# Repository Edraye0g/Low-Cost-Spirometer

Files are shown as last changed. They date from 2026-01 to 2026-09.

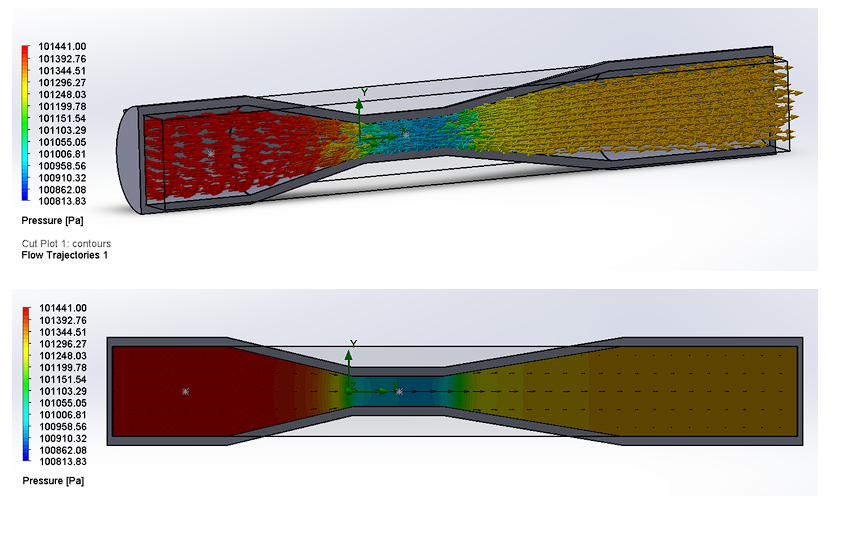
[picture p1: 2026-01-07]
figs, maps and diagrams/Screenshot 2026-01-07 191536.png

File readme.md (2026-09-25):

# Low-Cost Spirometer Design and Validation Document
(Tushil|Rayeed|Borshon|Nabil|Fuad)
## 1. Objective

The primary objectives of this experiment are given below:

* To design and simulate a Venturi-based transducer capable of measuring human respiratory flow rates (approx. $0\text{--}300\text{ L/min}$).

* To analyze the differential pressure generated across a $30\text{ mm}$ to $10\text{ mm}$ constriction using Computational Fluid Dynamics (Solidworks and SimScale).

* To implement a microcontroller-based data acquisition system using the MPX5010DP sensor to calculate real-time Flow Rate and Tidal Volume.

---

## 2. Introduction

### 2.1 Clinical Significance

Respiratory diseases, particularly Chronic Obstructive Pulmonary Disease (COPD) and Asthma, represent a major global health burden. According to the World Health Organization (WHO), COPD is the third leading cause of death worldwide, causing 3.23 million deaths in 2019. The primary diagnostic tool for these conditions is Spirometry, a pulmonary function test that measures the volume and speed of air inhaled and exhaled.

Key parameters measured include **Tidal Volume ($V_T$)**, the volume of air moved during normal breathing, and **Forced Vital Capacity (FVC)**, the total amount of air exhaled during a forced breath. Accurate monitoring of these parameters is critical for diagnosing airway obstruction and tracking disease progression.

### 2.2 Problem Statement

Standard clinical spirometers, often based on Fleisch pneumotachographs or ultrasonic sensors, provide high accuracy but come with significant barriers for low-resource settings. Commercial units typically cost between $1,70,000\text{ Tk}$ and $3,400\text{ Tk}$ and require frequent calibration and specialized maintenance. In rural healthcare facilities or developing regions, the lack of affordable diagnostic instrumentation leads to underdiagnosis and delayed treatment. Consequently, there is a pressing engineering need to develop low-cost, portable digital spirometers that maintain acceptable accuracy using off-the-shelf components.

### 2.3 Engineering Principle: The Venturi Effect

To address the cost barrier, this project utilizes a Venturi-based differential pressure transducer. Unlike turbine flow meters (which suffer from mechanical inertia) or hot-wire anemometers (which are fragile and computationally complex), a Venturi meter has no moving parts, making it robust and easy to sterilize.

The operation relies on the conservation of mass (Continuity Equation) and energy (Bernoulli's Principle). As air flows through a converging pipe, the fluid velocity must increase to pass through the narrower throat.

According to Bernoulli's Principle, this increase in kinetic energy (velocity) results in a simultaneous decrease in potential energy (static pressure). By placing pressure taps at the inlet (**Point 1**) and the throat (**Point 2**), the differential pressure ($\Delta P = P_1 - P_2$) can be measured.

### 2.4 Mathematical Derivation

The relationship between the measured pressure difference and the volumetric flow rate ($Q$) is derived for an incompressible fluid (approximated for low-speed airflow) as follows:
$$Q = C_d A_2 \sqrt{\frac{2\Delta P}{\rho(1 - \beta^4)}} \quad \text{--- (1)}$$

Where:

* $Q$: Volumetric flow rate ($\text{m}^3/\text{s}$)
* $C_d$: Discharge coefficient (accounts for viscous losses, typically $0.96\text{--}0.98$)
* $A_2$: Cross-sectional area of the throat ($\text{m}^2$)
* $\rho$: Density of air (approx. $1.225\text{ kg/m}^3$ at sea level)
* $\beta$: The Beta ratio ($d_{\text{throat}} / d_{\text{inlet}}$)

This non-linear relationship implies that flow is proportional to the square root of pressure ($Q \propto \sqrt{\Delta P}$). The system uses a differential pressure sensor (MPX5010DP) to convert $\Delta P$ into an analog voltage. The microcontroller then linearizes this signal and performs numerical integration over time ($V = \int Q \, dt$) to derive the total volume of air exhaled.

---

## 3. Literature Review

Recent developments in frugal biomedical engineering have demonstrated the viability of Venturi-based systems for respiratory monitoring. In a 2025 study, Wallace et al. designed and validated a low-cost spirometer utilizing the Venturi principle and 3D-printing technology for low-resource settings. Their device, which integrated a differential pressure sensor (MPX5010DP) with an Arduino microcontroller, was tested against a standard 2-liter calibration pump. The study reported a mean measured volume of $1.983\text{ L}$, resulting in an accuracy error of only $1.53\%$. Furthermore, their research highlighted that a throat diameter of approximately $10\text{ mm}$ is optimal for balancing sensor resolution with the maximum peak expiratory flow (PEF) of human subjects. This validates the design approach adopted in our experiment, confirming that differential pressure transduction is a reliable method for estimating tidal volume without expensive mechanical turbines.

---

## 4. Apparatus Required

### A. Mechanical & Simulation Tools

* **CAD Software:** SolidWorks (for geometry modeling)
* **CFD Solver:** SimScale (OpenFOAM based) and SolidWorks for pressure validation
* **3D Printer:** For fabricating the physical Venturi tube (PLA material)
* Scalp Vein Set

### B. Electronics Hardware

* **Microcontroller:** Arduino Uno (ATmega328P)
* **Pressure Sensor:** NXP MPX5010DP (Range: $0\text{--}10\text{ kPa}$, Sensitivity: $450\text{ mV/kPa}$)
* **Display:** 0.96" OLED Display ($128 \times 64$, I2C)
* Resistors
* Wires (Male to Male)

---

## 5. Design & Simulation

### Step 1: Mechanical Design

A Venturi tube was modeled with an ISO-standard inlet diameter of $30\text{ mm}$ to fit standard mouthpieces. To ensure a measurable pressure drop without exceeding the sensor's limit during peak expiration, the throat diameter was optimized to $10\text{ mm}$.

### Step 2: CFD Simulation (SimScale and SOLIDWORKS)

A steady-state simulation was performed to validate the design:

* **Physics:** Incompressible Fluid Flow.
* **Boundary Conditions:**
* **Inlet:** Velocity Inlet set to $3\text{ m/s}$ and $6\text{ m/s}$
* **Outlet:** Pressure Outlet at $0\text{ Pa}$ (Gauge)
* **Turbulence Model:** k-omega SST
* **Results:** The simulation predicted a pressure drop of $0.497\text{ kPa}$ and $2.021\text{ kPa}$.

### Step 3: Simulation Validation

**Table 1: Venturi Tube CFD Simulation Results for the value of constant $K$**

| Parameter | Inlet Velocity $3\text{ m/s}$ | Inlet Velocity $6\text{ m/s}$ |
| --- | --- | --- |
| **Density ($\text{kg/m}^3$)** | 1.20508| 1.20508|
| **Static Pressure inlet ($\text{kPa}$)** | 101.441| 101.795|
| **Static Pressure throat ($\text{kPa}$)** | 100.944| 99.774|
| **Pressure Differential $\Delta P$ ($\text{kPa}$)** | 0.497| 2.021|
| **Avg Static Pressure ($\text{kPa}$)** | 101.383| 101.561|
| **Avg Velocity ($\text{m/s}$)** | 3.0039| 6.023|
| **Volume Flow Rate ($\text{m}^3/\text{s}$)** | 0.00207598| 0.0042|
| **Value of $K$** | 201.2| 176.6|

$$\text{Average value of } K = \frac{201.2 + 176.6}{2} = 186.4$$

### Step 4: Signal Processing Algorithm & Arduino Simulation

The MPX5010DP outputs an analog voltage proportional to pressure. The Arduino performs the following operations:

1. **Analog-to-Digital Conversion (ADC):** Reads the $0\text{--}5\text{V}$ signal as a $0\text{--}1023$ integer.
2. **Pressure Calculation:** Converts voltage to Pascals.
3. **Flow Calculation:** Applies the simplified transfer function $Q = k\sqrt{\Delta P}$, where $k$ was determined to be $186.4$.
4. **Volume Integration:** Calculates Tidal Volume ($V_{\text{tidal}}$) by integrating flow over time:

$$V_{\text{tidal}} = \sum_{t=0}^{T} (Q_t \times \Delta t)$$

**Sensor Characterization:**
* **Sensitivity:** $0.45\text{ V/kPa}$
* **Zero Offset:** $\approx 0.20\text{ V}$ (Measured experimentally.
* **Algorithm Implementation:** $\text{Flow Rate} = Q_{\text{real}} = 186 \times \sqrt{P_{\text{measured}}}$

> **Fig. 3:** Spirometer operation sequence flowchart:
> 
> 
> `Start (Power on device)` $\rightarrow$ `Initialize System` $\rightarrow$ `Calibration (Calculate zero offset)` $\rightarrow$ `Read Sensor (Pin A0)` $\rightarrow$ `Filter Noise` $\rightarrow$ `Calculate Physics` $\rightarrow$ `Calculate Volume` $\rightarrow$ `Update Display (OLED)` $\rightarrow$ `Repeat`.
> 
> 

---

## 6. Methodology

### 6.1 Prototype Fabrication and Assembly

The Venturi tube was fabricated using Fused Deposition Modeling (FDM) 3D printing with Polylactic Acid (PLA) filament.

* **Print Settings:** To ensure air-tightness and structural integrity under pressure, the model was printed with 100% infill and a layer height of $0.12\text{ mm}$.

* **Sensor Integration:** The MPX5010DP differential pressure sensor was coupled to the Venturi tube using $4\text{ mm}$ silicone tubing. The "Pressure Port" ($P_1$) was connected to the inlet tap, and the "Vacuum Port" ($P_2$) was connected to the throat tap to measure the pressure drop ($\Delta P$).

* **Electronics:** The sensor output was wired to Analog Pin A0 of the microcontroller.

### 6.2 Calibration Protocol

Before human testing, a zero-point calibration was performed to eliminate sensor drift:

1. The device was placed on a stable, vibration-free surface.

2. The airflow path was left open to ambient air (zero flow condition).

3. The microcontroller recorded 50 consecutive readings over 0.5 seconds.

4. The average of these readings was stored as the `sensorOffset` voltage, which was subtracted from all subsequent measurements during the trial.

### 6.3 Human Testing Procedure

To validate the system's ability to measure Tidal Volume ($V_T$), tests were conducted on four healthy subjects (ages 20–24). The following protocol was strictly observed:

* **a) Sterilization:** The mouthpiece was sanitized with 70% isopropyl alcohol between subjects to maintain hygiene.

* **b) Posture:** Subjects were seated in an upright position with their feet flat on the floor to maximize thoracic expansion.

* **c) Sealing:** Subjects were instructed to hold the device horizontally and form a tight seal around the mouthpiece with their lips to prevent air leakage.

* **d) The Maneuver:**
1. *Phase 1 (Stabilization):* The subject breathed normally away from the device for 30 seconds.
2. *Phase 2 (Inhalation):* The subject took a standard resting inhalation.
3. *Phase 3 (Exhalation):* The subject exhaled normally (not forcefully) into the Venturi tube until their lungs reached functional residual capacity.

* **e) Data Logging:** The microcontroller sampled pressure data at $10\text{ Hz}$. The computed Flow Rate ($\text{L/min}$) and Accumulated Volume ($\text{L}$) were visualized in real-time on the OLED display.

### 6.4 Safety Precautions

* The device was operated at low voltages ($5\text{V}$) to ensure electrical safety.
* To prevent hyperventilation or dizziness, subjects were given a 60-second rest period between consecutive trials.

---

## 7. Verifying Low Cost

**Table 2: Components and Price Breakdown**

| No. | Component | Price (Tk.) |
| --- | --- | --- |
| 1 | MPX5010DP (Differential Pressure Sensor) | 2400|
| 2 | Arduino Uno R3 | 400|
| 3 | 0.96" OLED Display ($128 \times 64$, I2C) | 300|
| 4 | Breadboard | 50|
| 5 | 3D Printing | 200|
| 6 | Scalp Vein Set $\times 2$ | 20|
| **Total** |  | **$\approx 3,400\text{ Tk.}$**<br> |

---

## 8. Discussion

A comparative study was conducted on four subjects (**Ananna, Nowroz, Shakil, and Rayeed**). Their Tidal Volume ($V_T$) was measured first using a standard commercial spirometer (Control) and subsequently using the designed low-cost Venturi spirometer (Test).

### 8.1 Quantitative Performance

* **High Accuracy Cases:** For subjects Nowroz and Shakil, the device performed with high precision.

* **Nowroz:** Prototype $\approx 0.27\text{ L}$ vs. Standard $\approx 0.25\text{ L}$ (Difference: $+0.02\text{ L}$).

* **Shakil:** Prototype $\approx 0.42\text{ L}$ vs. Standard $\approx 0.45\text{ L}$ (Difference: $-0.03\text{ L}$).

* *Indication:* For low-to-medium flow rates, the calibrated transfer function is highly effective.

* **Deviation in Higher Volumes:** For subjects Ananna and Rayeed, a noticeable "underestimation" trend was observed.

* **Ananna:** Standard $\approx 0.53\text{ L}$ vs. Prototype $\approx 0.40\text{ L}$ (Error: $-24\%$).

* **Rayeed:** Standard $\approx 0.55\text{ L}$ vs. Prototype $\approx 0.46\text{ L}$ (Error: $\approx -16\%$).

### 8.2 Error Analysis & Engineering Constraints

1. **Air Leakage:** Minor air leakage at the interface between the rigid 3D-printed PLA mouthpiece and the subject's mouth caused exhaled air to bypass the Venturi throat.

2. **Discharge Coefficient Non-Linearity:** The algorithm assumes a constant $C_d$, but $C_d$ varies with Reynolds number. At higher flow rates, turbulence causes energy losses not fully captured by $Q = k\sqrt{P}$.

3. **Sensor Response Lag & Sampling Rate:** Numerical integration ($\sum \text{Flow} \times \Delta t$) sampled at $10\text{ Hz}$ may miss the rapid peak flow of a strong breath, leading to volume under-calculation.

### 8.3 Economic Feasibility (Cost-Benefit Analysis)

* **Traditional Device Cost:** $\approx 170,000\text{ BDT (Tk)}$

* **Low-Cost Prototype Cost:** $\approx 3,400\text{ BDT (Tk)}$

* **Cost Reduction:** $\approx 97.8\%$ (Roughly 45 times cheaper)

### 8.4 The Cost-Utility Trade-off

While standard spirometers ($170,000\text{ Tk}$) are necessary for diagnostic confirmation requiring $<3\%$ error, the proposed device ($3,400\text{ Tk}$) is ideal for mass screening in rural healthcare centers (Upazila Health Complexes). It effectively distinguishes between normal and abnormal respiratory patterns at a fraction of the cost.

### 8.5 Conclusion on Viability

The prototype successfully categorizes patients within their correct tidal volume ranges. Future iterations can bridge the accuracy gap by implementing a non-linear calibration curve via software and a silicone-sealed mouthpiece via hardware.

---

## 9. References

1. World Health Organization (WHO), "Chronic obstructive pulmonary disease (COPD)," Fact sheet. [Online]. Available: [https://www.who.int/news-room/fact-sheets/detail/chronic-obstructive-pulmonary-disease-(copd)](https://www.who.int/news-room/fact-sheets/detail/chronic-obstructive-pulmonary-disease-(copd)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)

2. J. E. Hall, M. E. Hall, and A. C. Guyton, *Guyton and Hall textbook of medical physiology*, 14th edition. Philadelphia, PA: Elsevier, 2021.

3. C. W. Carspecken, C. Arteta, and G. D. Clifford, "TeleSpiro: A low-cost mobile spirometer for resource-limited settings," in *2013 IEEE Point-of-Care Healthcare Technologies (PHT)*, Bangalore, India: IEEE, Jan. 2013, pp. 144-147. doi: `10.1109/PHT.2013.6461305`.

4. B. R. Munson, Ed., *Fundamentals of fluid mechanics*, 7th ed. Hoboken, NJ: Wiley, 2013.

5. J. Wallace, P. C. Rifá, T. Kannathasan, C. F. Hayfron-Benjamin, P. Anyanwu, and D. Piaggio, "Design, Manufacture and Validation of a Spirometry Device aimed for Low-Resource Settings," June 11, 2025, *In Review*. doi: `10.21203/rs.3.rs-6812011/v1`.

---

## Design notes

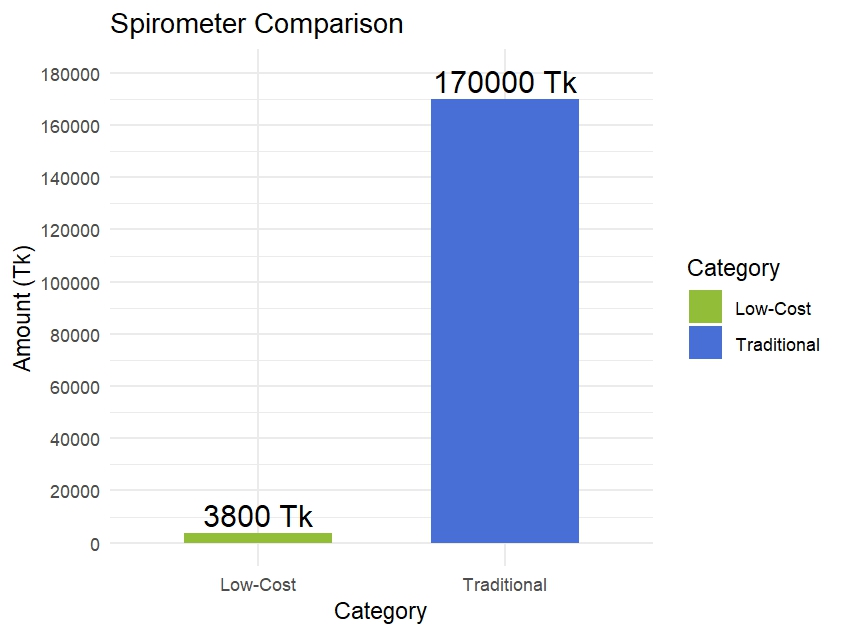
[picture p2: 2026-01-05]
spirometer comp.jpeg

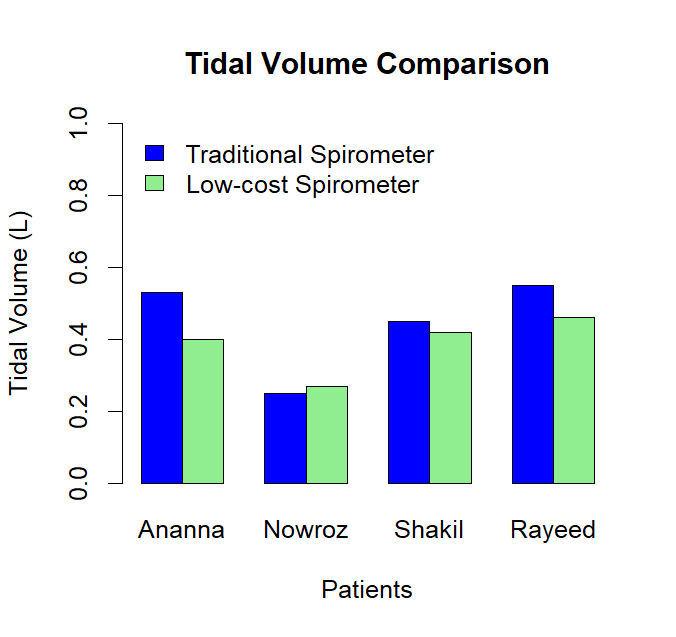
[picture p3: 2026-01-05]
comparison with patients.png

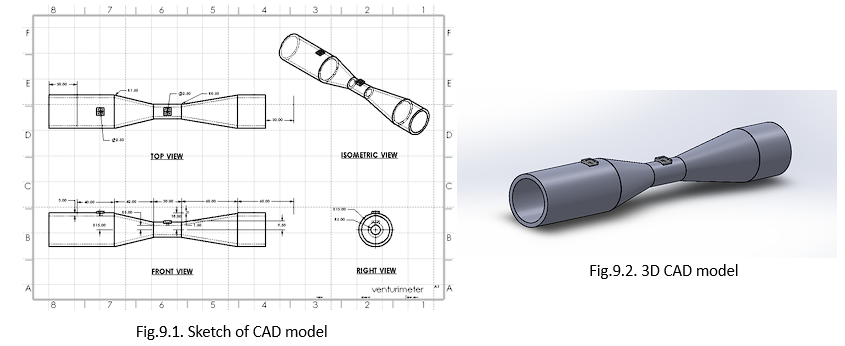
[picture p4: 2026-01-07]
figs, maps and diagrams/Screenshot 2026-01-07 191712.png

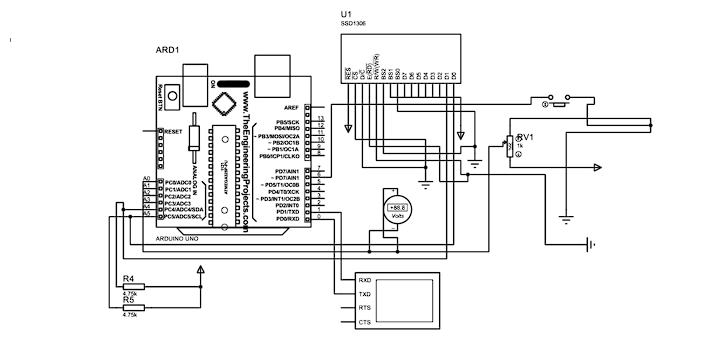
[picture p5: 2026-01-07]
figs, maps and diagrams/Screenshot 2026-01-07 191753.png

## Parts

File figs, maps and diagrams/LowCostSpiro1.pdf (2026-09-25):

## 1. Objective

The primary objectives of this experiment are given below:

- To design and simulate a Venturi-based transducer capable of measuring human respiratory flow rates (approx. 0–300 L/min).
- To analyze the differential pressure generated across a 30mm to 10mm constriction using Computational Fluid Dynamics (Solidworks and SimScale).
- To implement a microcontroller-based data acquisition system using the MPX5010DP sensor to calculate real-time Flow Rate and Tidal Volume.

## 2. Introduction

### 2.1 Clinical Significance

Respiratory diseases, particularly Chronic Obstructive Pulmonary Disease (COPD) and Asthma, represent a major global health burden. According to the World Health Organization (WHO), COPD is the third leading cause of death worldwide, causing 3.23 million deaths in 2019[1]. The primary diagnostic tool for these conditions is Spirometry, a pulmonary function test that measures the volume and speed of air inhaled and exhaled.

Key parameters measured include Tidal Volume (VT), the volume of air moved during normal breathing, and Forced Vital Capacity (FVC), the total amount of air exhaled during a forced breath [2]. Accurate monitoring of these parameters is critical for diagnosing airway obstruction and tracking disease progression.

### 2.2 Problem Statement

Standard clinical spirometers, often based on Fleisch pneumotachographs or ultrasonic sensors, provide high accuracy but come with significant barriers for low-resource settings. Commercial units typically cost between 1,70,000Tk and 3,400Tk and require frequent calibration and specialized maintenance[3]. In rural healthcare facilities or developing regions, the lack of affordable diagnostic instrumentation leads to underdiagnosis and delayed treatment. Consequently, there is a pressing engineering need to develop low-cost, portable digital spirometers that maintain acceptable accuracy using off-the-shelf components.

### 2.3 Engineering Principle: The Venturi Effect

To address the cost barrier, this project utilizes a Venturi-based differential pressure transducer. Unlike turbine flow meters (which suffer from mechanical inertia) or hot-wire anemometers (which are fragile and computationally complex), a Venturi meter has no moving parts, making it robust and easy to sterilize.

The operation relies on the conservation of mass (Continuity Equation) and energy (Bernoulli’s Principle). As air flows through a converging pipe, the fluid velocity must increase to pass through the narrower throat.

According to Bernoulli’s Principle, this increase in kinetic energy (velocity) results in a simultaneous decrease in potential energy (static pressure)[4]. By placing pressure taps at the inlet (Point 1) and the throat (Point 2), the differential pressure (ΔP = P1 − P2) can be measured.

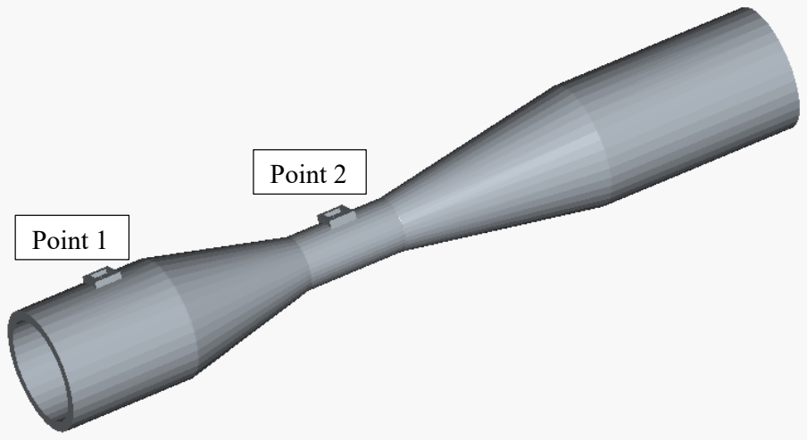
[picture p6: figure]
Point 1; Point 2

Fig. 1. A SOLIDWORKS designed Venturi-meter.

### 2.4 Mathematical Derivation

The relationship between the measured pressure difference and the volumetric flow rate (Q) is derived for an incompressible fluid (approximated for low-speed airflow) as follows:

Q = CdA2√
2ΔP
ρ(1−β⁴) | (1)

Where:

Q: Volumetric flow rate (m³
/s)

Cd: Discharge coefficient (accounts for viscous losses, typically 0.96–0.98)

A2: Cross-sectional area of the throat (m²
)

ρ : Density of air (approx. 1.225 kg/m³
at sea level)

β : The Beta ratio (d(tℎroat)/d(inlet)

This non-linear relationship implies that flow is proportional to the square root of pressure (Q ∝ √ΔP). The system uses a differential pressure sensor (MPX5010DP) to convert ΔP into an analog voltage. The microcontroller then linearizes this signal and performs numerical integration over time (V = ∫ Q dt) to derive the total volume of air exhaled.

## 3. Literature Review

Recent developments in frugal biomedical engineering have demonstrated the viability of Venturi-based systems for respiratory monitoring. In a 2025 study, Wallace et al. designed and validated a low-cost spirometer utilizing the Venturi principle and 3D-printing technology for low-resource settings. Their device, which integrated a differential pressure sensor (MPX5010DP) with an Arduino microcontroller, was tested against a standard 2-liter calibration pump. The study reported a mean measured volume of 1.983 L, resulting in an accuracy error of only 1.53%[5]. Furthermore, their research highlighted that a throat diameter of approximately 10mm is optimal for balancing sensor resolution with the maximum peak expiratory flow (PEF) of human subjects. This validates the design approach adopted in our experiment, confirming that differential pressure transduction is a reliable method for estimating tidal volume without expensive mechanical turbines.

## 4. Apparatus Required

A. Mechanical & Simulation Tools:
- CAD Software: SolidWorks (for geometry modeling).
- CFD Solver: SimScale (OpenFOAM based) and SolidWorks for pressure validation.
- 3D Printer: For fabricating the physical Venturi tube (PLA material).
- Scalp Vein Set
B. Electronics Hardware:
- Microcontroller: Arduino Uno (ATmega328P).
- Pressure Sensor: NXP MPX5010DP (Range: 0–10 kPa, Sensitivity: 450 mV/kPa).
- Display: 0.96" OLED Display (128x64, I2C).
- Resistors.
- Wires (Male to Male).

## 5. Design & Simulation

Step 1: Mechanical Design

A Venturi tube was modeled with an ISO-standard inlet diameter of 30mm to fit standard mouthpieces. To ensure a measurable pressure drop without exceeding the sensor's limit during peak expiration, the throat diameter was optimized to 10mm.

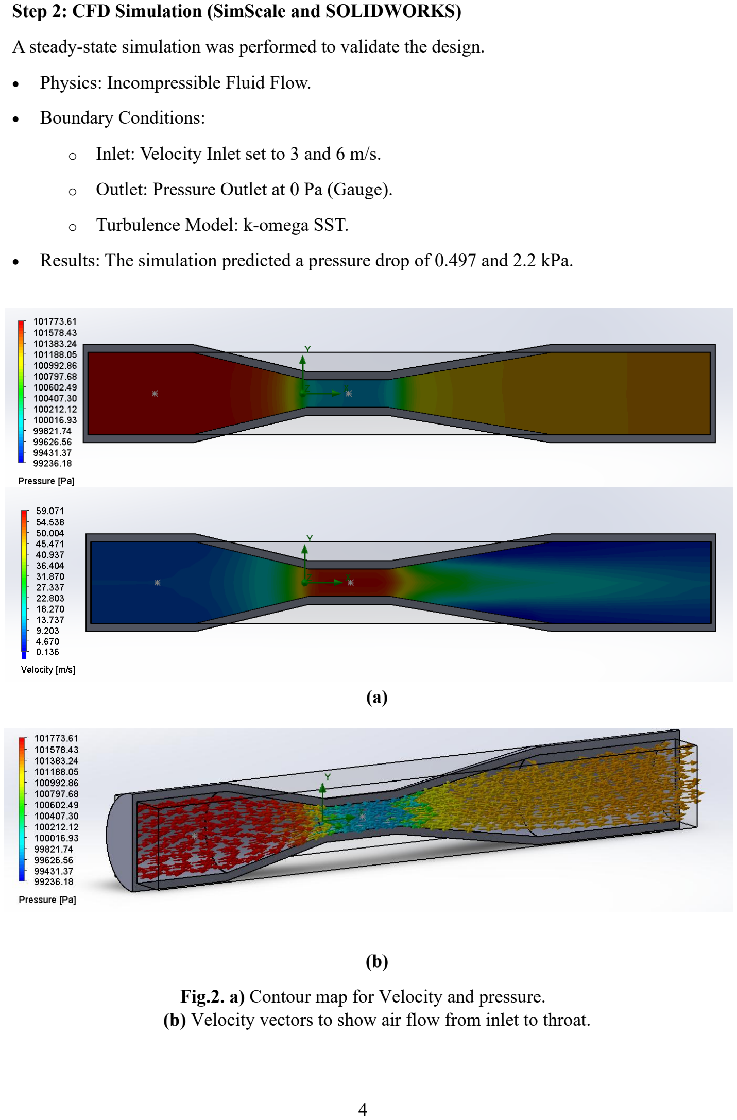
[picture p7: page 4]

Step 2: CFD Simulation (SimScale and SOLIDWORKS)

A steady-state simulation was performed to validate the design.

- Physics: Incompressible Fluid Flow.
- Boundary Conditions:
- Inlet: Velocity Inlet set to 3 and 6 m/s.
- Outlet: Pressure Outlet at 0 Pa (Gauge).
- Turbulence Model: k-omega SST.
- Results: The simulation predicted a pressure drop of 0.497 and 2.2 kPa.

(a)

(b)

Fig.2. a) Contour map for Velocity and pressure.
(b) Velocity vectors to show air flow from inlet to throat.

Step 3: Simulation Validation

Table:1 Venturi Tube CFD Simulation Results for the value of constant K

Parameter | Inlet Velocity 3 m/s | Inlet Velocity 6 m/s
Density (kg/m³) | 1.20508 | 1.20508
Static Pressure inlet (kPa) | 101.441 | 101.795
Static Pressure thoat (kPa) | 100.944 | 99.774
Pressure Differential ΔP (kPa) | 0.497 | 2.021
Avg Static Pressure (kPa) | 101.383 | 101.561
Avg Velocity (m/s) | 3.0039 | 6.023
Volume Flow Rate (m³/s) | 0.00207598 | 0.0042
Value of K | 201.2 | 176.6

So, Average value of K = (201.2 + 176.6)/2 = 186.4

Step 3: Signal Processing Algorithm

The MPX5010DP outputs an analog voltage proportional to pressure. The Arduino performs the following operations:

- Analog-to-Digital Conversion (ADC): Reads the 0-5V signal as a 0-1023 integer.
- Pressure Calculation: Converts voltage to Pascals.
- Flow Calculation: Applies the simplified transfer function Q = k √{Δ p}, where k was determined to be 186.4.
- Volume Integration: Calculates Tidal Volume (Vtidal) by integrating flow over time: Vtidal = ∑ (Qt × Δt)

T
| t=0

Step 4: Arduino Simulation

Electronic Data Validation (Arduino)

The MPX5010DP sensor outputs an analog voltage proportional to pressure. The Arduino interprets this data using the calibration constants derived from the CFD simulation.

- Sensor Characterization:
- Sensitivity: 0.45 V/kPa.
- Zero Offset: ≈ 0.20 V(Measured experimentally).
- Calibration Factor (k) Derivation:

Therefore, the Arduino algorithm implemented is: Flow Rate = Qreal = 186 × √Pmeasured

Volume Integration: Calculates Tidal Volume (Vtidal) by integrating flow over time: Vtidal = ∑ (Qreal × Δt)

T
| t=0

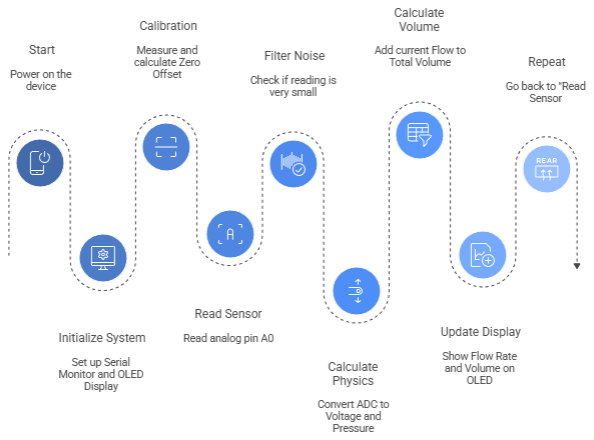
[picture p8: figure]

Fig. 3. Spirometer operation sequence

## 6. Methodology

### 6.1 Prototype Fabrication and Assembly

The Venturi tube was fabricated using Fused Deposition Modeling (FDM) 3D printing with Polylactic Acid (PLA) filament.

- Print Settings: To ensure air-tightness and structural integrity under pressure, the model was printed with 100% infill and a layer height of 0.12mm.
- Sensor Integration: The MPX5010DP differential pressure sensor was coupled to the Venturi tube using 4mm silicone tubing. The "Pressure Port" (P1) was connected to the inlet tap, and the "Vacuum Port" (P2) was connected to the throat tap to measure the pressure drop (ΔP).
- Electronics: The sensor output was wired to the Analog Pin A0 of the microcontroller.

### 6.2 Calibration Protocol

Before human testing, a zero-point calibration was performed to eliminate sensor drift:

- The device was placed on a stable, vibration-free surface.
- The airflow path was left open to ambient air (zero flow condition).
- The microcontroller recorded 50 consecutive readings over 0.5 seconds.
- The average of these readings was stored as the sensorOffset voltage, which was subtracted from all subsequent measurements during the trial.

### 6.3 Human Testing Procedure

To validate the system's ability to measure Tidal Volume (VT), tests were conducted on four healthy subjects (ages 20–24). The following protocol was strictly observed to ensure data consistency:

a) sterilization: The mouthpiece was sanitized with 70% isopropyl alcohol between subjects to maintain hygiene.
b) Posture: Subjects were seated in an upright position with their feet flat on the floor to maximize thoracic expansion.
c) Sealing: Subjects were instructed to hold the device horizontally and form a tight seal around the mouthpiece with their lips to prevent air leakage.
d) The Maneuver:
i. Phase 1 (Stabilization): The subject breathed normally away from the device for 30 seconds.
ii. | Phase 2 (Inhalation): The subject took a standard resting inhalation.
iii. | Phase 3 (Exhalation): The subject exhaled normally (not forcefully) into the Venturi tube until their lungs reached functional residual capacity.

e) Data Logging: The microcontroller sampled the pressure data at a frequency of 10 Hz. The computed Flow Rate (L/min) and Accumulated Volume (L) were visualized in real-time on the OLED display.

### 6.4 Safety Precautions

- The device was operated at low voltages (5V) to ensure electrical safety.
- To prevent hyperventilation or dizziness, subjects were given a 60-second rest period between consecutive trials

## 7. Verifying Low Cost

Table-2 represents the components with price to verify low-cost production and reproducibility:

No. | Component | Price (Tk.) ≈ BDT 3400Tk
1. | MPX5010DP (Differential Pressure Sensor) | 2400
2. | Arduino Uno R3 | 400
3. | 0.96’’ OLED Display (128×64, I2C) | 300
4. | Breadboard | 50
5. | 3D Printing | 200
6. | Scalp Vein Set X2 | 20

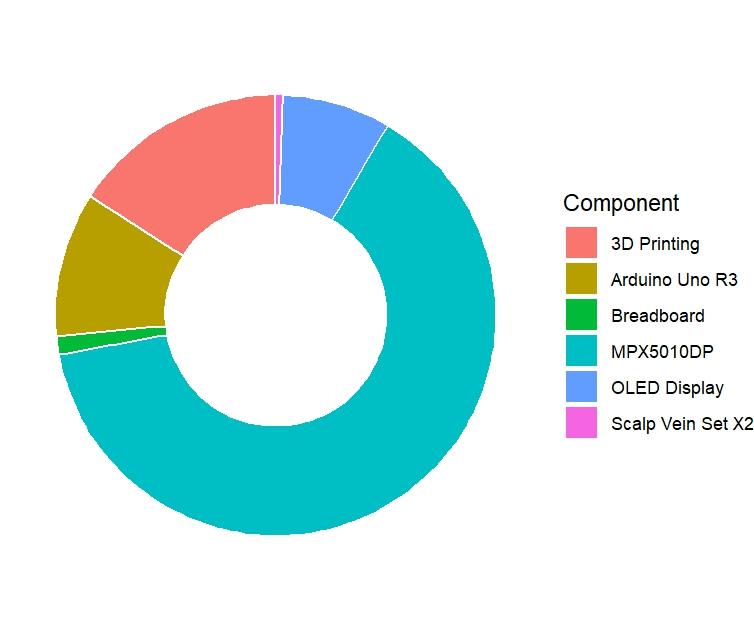
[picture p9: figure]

Fig.4. Costs on different Components.

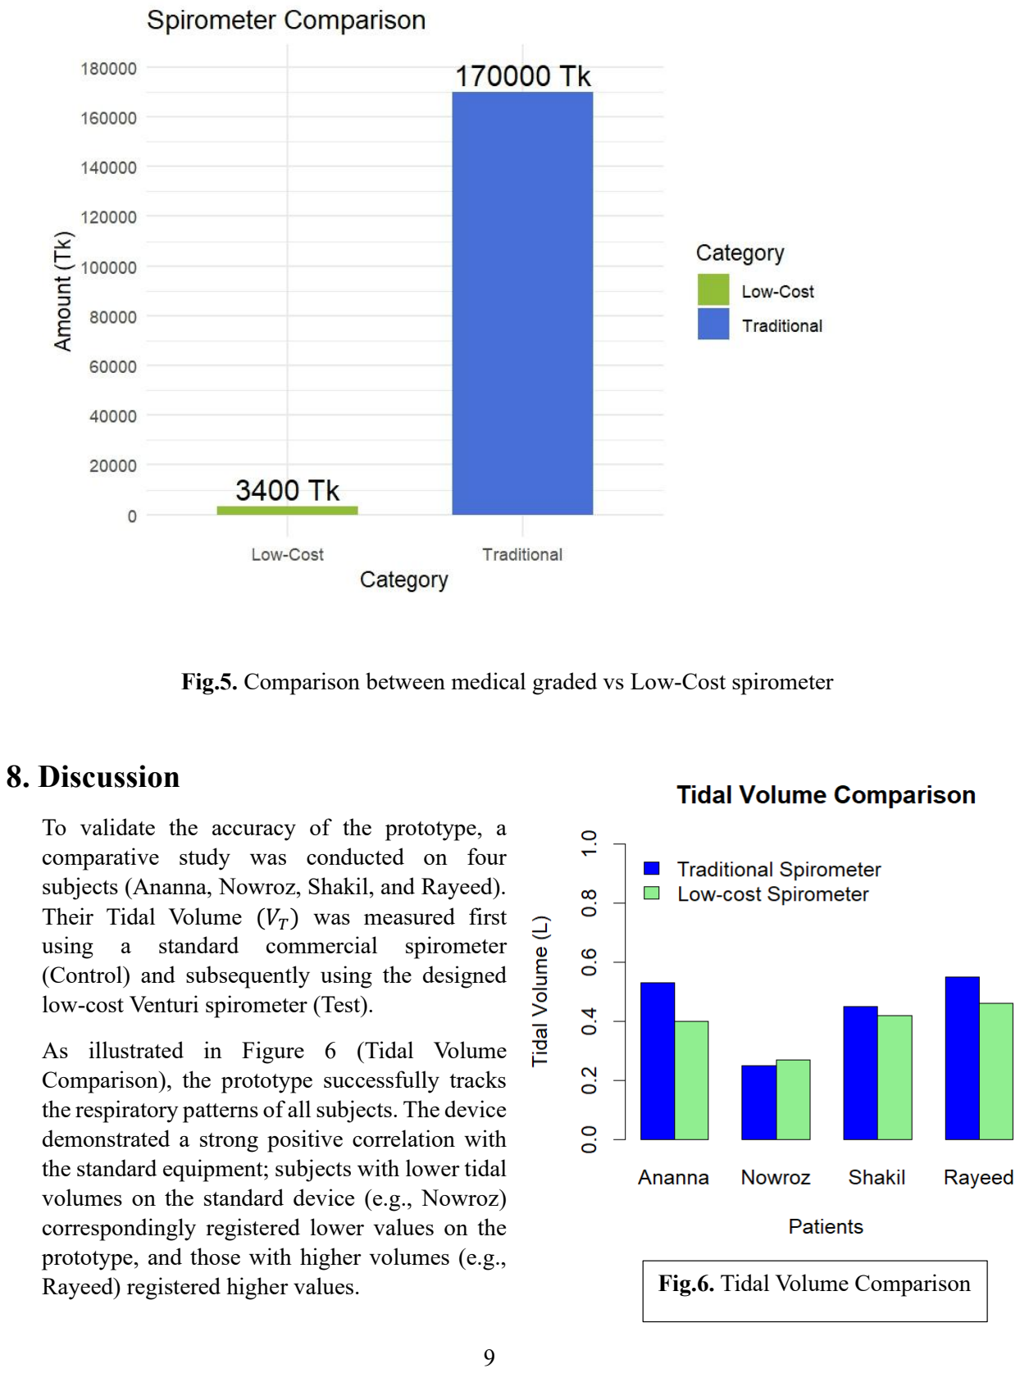
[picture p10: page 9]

Fig.5. Comparison between medical graded vs Low-Cost spirometer

## 8. Discussion

To validate the accuracy of the prototype, a comparative study was conducted on four subjects (Ananna, Nowroz, Shakil, and Rayeed). Their Tidal Volume (VT) was measured first
using | a | standard | commercial | spirometer
(Control) and subsequently using the designed low-cost Venturi spirometer (Test).

As illustrated in Figure 6 (Tidal Volume Comparison), the prototype successfully tracks the respiratory patterns of all subjects. The device demonstrated a strong positive correlation with the standard equipment; subjects with lower tidal volumes on the standard device (e.g., Nowroz)
correspondingly registered lower values on the
prototype, and those with higher volumes (e.g.,
Rayeed) registered higher values. | Fig.6. Tidal Volume Comparison

### 8.1 Quantitative Performance

- High Accuracy Cases: For subjects Nowroz and Shakil, the device performed with high precision.
- Nowroz: The prototype measured ≈ 0.27L against the standard ≈ 0.25L (Difference: +0.02L).
- Shakil: The prototype measured ≈ 0.42L against the standard ≈ 0.45L (Difference: −0.03L).
- This indicates that for low-to-medium flow rates, the calibrated transfer function (Q = 46.5√P) is highly effective.
- Deviation in Higher Volumes: For subjects Ananna and Rayeed, a noticeable "underestimation" trend was observed.
- Ananna: Standard ≈ 0.53L vs. Prototype ≈ 0.40L (Error:≈ −24%)
- Rayeed: Standard ≈ 0.55L vs. Prototype ≈ 0.46L (Error: ≈ −16%).

### 8.2 Error Analysis & Engineering Constraints

The observed underestimation at higher tidal volumes (Ananna and Rayeed) highlights specific engineering challenges:

1. Air Leakage: The most probable cause for the volume loss is minor air leakage at the interface between the 3D-printed mouthpiece and the subject's mouth. Unlike commercial soft-seal mouthpieces, the rigid PLA plastic may not form a perfect seal, leading to a fraction of the exhaled air bypassing the Venturi throat.
2. Discharge Coefficient Non-Linearity: The algorithm assumes a constant discharge coefficient (Cd

) across all flow rates. In reality, Cd varies slightly with Reynolds number. At higher flow rates (larger breaths), increased turbulence may cause energy losses that the simplified equation (Q = k√P) does not fully account for, resulting in a lower calculated volume.

3. Sensor Response Lag: While the MPX5010DP is fast, the numerical integration method (∑Flow × Δt) is sensitive to sampling frequency. If the rapid peak flow of a strong breath is not sampled frequently enough, the integration area (Volume) will be under-calculated.

### 8.3 Economic Feasibility (Cost-Benefit Analysis)

A primary objective of this project was to lower the barrier to entry for respiratory diagnosis. Figure 5 (Spirometer Comparison) illustrates the dramatic cost disparity between the developed prototype and a standard clinical spirometer.

- Traditional Device Cost: ≈ 170,000 BDT (Tk).
- Low-Cost Prototype Cost: ≈ 3,400 BDT (Tk).

This represents a cost reduction of approximately 97.8%, making the prototype roughly 45 times cheaper than the commercial alternative.

### 8.4 The Cost-Utility Trade-off

Analyzing both datasets reveals a significant engineering trade-off. While the prototype exhibits a slight reduction in accuracy at higher air volumes (Figure 6), the cost benefit is exponential (Figure 5).

In a clinical hierarchy, standard spirometers (170,000Tk) are necessary for "Diagnostic Confirmation" where <3% error is required. However, for "Mass Screening" in rural healthcare centers (Upazila Health Complexes), the proposed device (3,400Tk) provides a viable solution. It effectively distinguishes between healthy and abnormal respiratory patterns (as seen in the difference between Nowroz and Rayeed's volumes) at a fraction of the cost.

### 8.5 Conclusion on Viability

Despite the deviations in higher-volume subjects, the device successfully categorizes patients within their correct tidal volume ranges. The error margins observed in Nowroz and Shakil are well within the acceptable limits for a screening device. The systematic underestimation seen in other subjects suggests that a variable calibration factor (increasing k for higher pressures) or an improved mouthpiece seal could bring the accuracy to clinical standards.

The data suggests that the developed spirometer is not a replacement for high-end hospital equipment but is an optimal screening tool. The minor loss in absolute accuracy is acceptable given the massive accessibility it grants to under-resourced healthcare facilities. Future iterations could bridge the accuracy gap by implementing a non-linear calibration curve (software update) and a silicone-sealed mouthpiece (hardware update) without significantly increasing the manufacturing cost.

## 9. References:

[1] , [Online]. Available: https://www.who.int/news-room/fact-sheets/detail/chronic-obstructive-pulmonary-disease-(copd)
[2] J. E. Hall, M. E. Hall, and A. C. Guyton, Guyton and Hall textbook of medical physiology, 14th edition. Philadelphia, PA: Elsevier, 2021.
[3] C. W. Carspecken, C. Arteta, and G. D. Clifford, “TeleSpiro: A low-cost mobile spirometer for resource-limited settings,” in 2013 IEEE Point-of-Care Healthcare Technologies (PHT), Bangalore, India: IEEE, Jan. 2013, pp. 144–147. doi: 10.1109/PHT.2013.6461305.
[4] B. R. Munson, Ed., Fundamentals of fluid mechanics, 7. ed. Hoboken, NJ: Wiley, 2013.
[5] J. Wallace, P. C. Rifá, T. Kannathasan, C. F. Hayfron-Benjamin, P. Anyanwu, and D. Piaggio, “Design, Manufacture and Validation of a Spirometry Device aimed for Low-Resource Settings,” June 11, 2025, In Review. doi: 10.21203/rs.3.rs-6812011/v1.

## 10. Git Repository

Everything in the project is uploaded in the Github repository link:

https://github.com/Edraye0g/Low-Cost-Spirometer.git

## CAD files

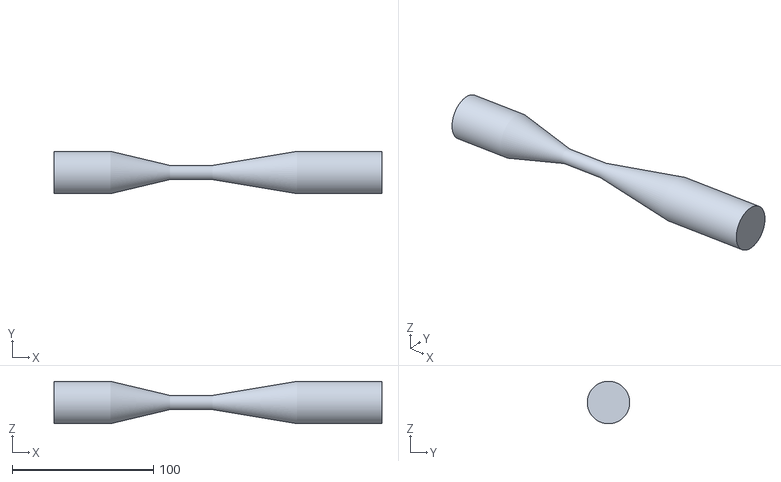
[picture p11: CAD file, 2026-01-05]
Venturi-meter-Body/wallMentioned.stl
232.0 x 30.0 x 30.0

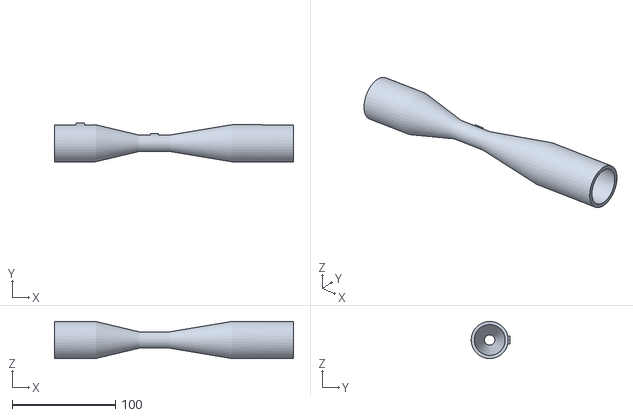
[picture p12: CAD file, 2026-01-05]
venturimeter final.stl
232.0 x 37.5 x 36.0

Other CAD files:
Venturi-meter-Body/Ventu.stp

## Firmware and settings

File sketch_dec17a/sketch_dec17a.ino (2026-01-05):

#include <Wire.h>
#include <Adafruit_GFX.h>
#include <Adafruit_SSD1306.h>

// --- SCREEN SETTINGS ---
#define SCREEN_WIDTH 128
#define SCREEN_HEIGHT 64
#define OLED_RESET    -1 
Adafruit_SSD1306 display(SCREEN_WIDTH, SCREEN_HEIGHT, &Wire, OLED_RESET);

// --- HARDWARE ---
const int sensorPin = A0;   
const int buttonPin = 2;    

// --- CALIBRATION ---
float sensorOffset = 0; 

// 1. STABLE K (As requested)
float k_constant = 46.5; 

// 2. VOLUME MULTIPLIER (The Magic Fix)
// Since k=46.5 gives ~0.3L, we multiply by 1.7 to get ~0.5L
// accurate volume without adding noise.
float VOLUME_SCALER = 1.7; 

// --- SMOOTHING ---
float filteredValue = 0.0;  
float alpha = 0.1;          

// --- VARIABLES ---
unsigned long previousMillis = 0;   
unsigned long lastDisplayTime = 0;  
unsigned long breathStopTimer = 0;  

float currentVol = 0.0;        
float peakFlow = 0.0;
float previousFlow = 0.0; 
bool isBreathing = false;           

// --- THRESHOLDS ---
// Low thresholds to catch the full breath, relying on Deadzone for silence
const float START_THRESHOLD = 2.0;  
const float CUTOFF_THRESHOLD = 1.0; 
const int BREATH_TIMEOUT = 1000;    // Wait 1 sec to confirm stop

void setup() {
  Serial.begin(9600);
  if(!display.begin(SSD1306_SWITCHCAPVCC, 0x3C)) { for(;;); }
  pinMode(buttonPin, INPUT_PULLUP); 
   
  // Calibration
  display.clearDisplay();
  display.setTextColor(WHITE);
  display.setTextSize(1);
  display.setCursor(10, 20);
  display.println("CALIBRATING...");
  display.setCursor(10, 35);
  display.println("Stay Still...");
  display.display();
  delay(1500); 

  long total = 0;
  for(int i=0; i<50; i++){
    total += analogRead(sensorPin);
    delay(5);
  }
  sensorOffset = total / 50.0;
   
  display.clearDisplay();
  previousMillis = millis(); 
}

void loop() {
  // 1. Time
  unsigned long currentMillis = millis();
  float dt = (currentMillis - previousMillis) / 1000.0; 
  previousMillis = currentMillis;

  // 2. Read Sensor
  float rawValue = analogRead(sensorPin);
  float adjustedValue = rawValue - sensorOffset;
  
  // --- 3. ZERO LOCK (DEADZONE) ---
  // If the raw sensor value is tiny (noise 1, 2, or 3), FORCE it to 0.
  // This guarantees the math hits 0.00 and the breath STOPS.
  if (adjustedValue < 5.4) {
    adjustedValue = 0;
  }

  // Smooth the data
  filteredValue = (filteredValue * (1.0 - alpha)) + (adjustedValue * alpha);

  // 4. Physics
  float voltage = filteredValue * (5.0 / 1023.0);
  float pressurePa = (voltage / 0.45) * 1000.0;
   
  float flowRate = 0;
  if (pressurePa > 0) {
    flowRate = k_constant * sqrt(pressurePa / 1000.0); 
  }

  // 5. Volume Integration
  if (flowRate > START_THRESHOLD) {
    isBreathing = true;
    breathStopTimer = millis(); 
    if (flowRate > peakFlow) peakFlow = flowRate;
  }

  if (isBreathing && flowRate > CUTOFF_THRESHOLD) {
     float averageFlow = (flowRate + previousFlow) / 2.0;
     
     // We calculate raw volume here...
     float instantVol = (averageFlow / 60.0) * dt;
     
     // ...and apply the SCALER here to get to 0.5L
     currentVol += (instantVol * VOLUME_SCALER);
  }
  previousFlow = flowRate;

  // 6. Stop Logic
  if (isBreathing) {
     // Because of the Zero Lock, flowRate will definitely hit 0.0 here
     if (flowRate <= CUTOFF_THRESHOLD) {
        if (millis() - breathStopTimer > BREATH_TIMEOUT) {
           showResultsWindow(); 
           
           isBreathing = false;
           currentVol = 0;
           peakFlow = 0;
           filteredValue = 0; 
           previousFlow = 0; 
        }
     }
  }

  // 7. Update Screen
  if (millis() - lastDisplayTime > 150) {
    updateLiveScreen(flowRate);
    lastDisplayTime = millis();
  }
}

void updateLiveScreen(float flow) {
  display.clearDisplay();
  display.setTextSize(1);
  display.setCursor(0, 0);
  display.print("LIVE");
  display.drawLine(0, 10, 128, 10, WHITE);

  display.setTextSize(2);
  display.setCursor(0, 20);
  display.print(flow, 1); 
  display.setTextSize(1);
  display.print(" L/m");

  display.setCursor(0, 45);
  display.print("Vol: ");
  display.print(currentVol, 2); 
  display.print(" L");

  // Bar Graph
  int maxScale = (peakFlow > 100) ? 600 : 100;
  int barFlow = flow; if (barFlow > maxScale) barFlow = maxScale; 
  int barWidth = map(barFlow, 0, maxScale, 0, 128); 
  display.fillRect(0, 56, barWidth, 8, WHITE);
  display.display();
}

void showResultsWindow() {
  display.clearDisplay();
  display.setTextSize(1);
  display.setCursor(0, 0);
  display.print("--- RESULT ---");
  display.drawLine(0, 10, 128, 10, WHITE);

 // 1. Peak Flow Rate
  display.setCursor(0, 20);
  display.setTextSize(1);
  display.println("MAX FLOW RATE:");
  
  display.setTextSize(1.4);
  display.print(peakFlow, 1);
  display.setTextSize(1);
  display.println(" L/min");

  // 2. Tidal Volume
  display.setCursor(0,37);
  display.setTextSize(1);
  display.println("TIDAL VOLUME:");
  
  display.setTextSize(2);
  display.print(currentVol, 3); 
  display.setTextSize(1);
  display.println(" L");

  display.setTextSize(1);
  display.setCursor(80, 55);
  display.print("[RESET]");
  display.display();
  
  while(digitalRead(buttonPin) == HIGH) { }
  
  display.clearDisplay();
  display.setCursor(40, 30);
  display.print("RESET!");
  display.display();
  delay(500); 
  previousMillis = millis(); 
  filteredValue = 0; 
  previousFlow = 0;
}

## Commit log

2026-01-05 Add Arduino code for breath monitoring system
2026-01-05 Circuit diagram
2026-01-07 Update Arduino code for UNO
